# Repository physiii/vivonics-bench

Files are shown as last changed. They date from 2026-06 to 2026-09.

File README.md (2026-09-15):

# Vivonics Bench

Standalone hardware-bench repository for Vivonics shared-optical-metrology and
operator-material-screen work. The parent Vivonics repo consumes this
repository as its `bench/` Git submodule. It owns
both the Raspberry Pi measurement service and the ESP32-S3 laser-controller
firmware/circuit package.

The Pi owns the tight first-loop instrumentation:

- HDMI projector pattern display
- `IMX477` camera capture through `rpicam` / RTSP frame grabs
- USB-first control and telemetry for the ESP32-S3 four-source laser controller,
  with automatic Wi-Fi fallback
- optional `TSL2591` and `AS7341` I2C sensor snapshots
- later BPW34 photodiode data only after an ESP32/external ADC or TIA path

## Files

- `bench_service.py`: FastAPI service for projector/camera/sensor runs.
- `x1_measurement.py`: file-backed CLI smoke-test runner.
- `capture.py`, `projector.py`, `sensors.py`: hardware adapters.
- `laser_gpio.py`: Raspberry Pi GPIO outputs for red / green laser switching.
- `laser_controller_client.py`: persistent USB owner, normalized ADC telemetry,
  independent four-source control, and Wi-Fi fallback.
- `photocycle.py`: metrology and operator-screen red-linearity and green-write/red-read protocols.
- `install.sh`: user systemd service installer for `vivonics-bench`.
- `scripts/deploy_remote.sh`: workstation-to-Pi deploy helper.
- `laser_controller/`: authoritative ESP32-S3 firmware, KiCad design, review
  gates, and first-article support files for the fabricated laser controller.

## Install on the Pi

```bash
cd /home/andy/vivonics/pi  # standalone deployment path on the Pi
./install.sh
sudo raspi-config nonint do_i2c 0
```

`install.sh` creates a repo-local `.venv` so Raspberry Pi OS PEP 668 system
Python protection does not block dependency installation.

Check I2C sensor visibility:

```bash
/usr/sbin/i2cdetect -y 1
python3 x1_measurement.py sensor-check
```

Run the bench service:

```bash
./install.sh
curl http://raspberrypi.local:8090/status
curl http://raspberrypi.local:8090/sensors
```

## Laser GPIO Wiring

Use these Raspberry Pi BCM pins:

| Channel | BCM GPIO | Physical pin |
| --- | ---: | ---: |
| Red laser enable | `GPIO15` | `10` |
| Green laser enable | `GPIO24` | `18` |

Do not power or ground a laser module directly through a Pi GPIO pin. Use each
GPIO as a logic signal into a low-side MOSFET or transistor switch, with the
laser supply ground tied to Pi ground. The Pi pin drives the gate/base; laser
negative goes to the MOSFET drain / transistor collector; source / emitter goes
to ground. Keep the laser module's own current limiting or driver in place.

The camera-bench user service defaults to `VIVONICS_LIGHT_DRIVER=controller`.
It holds `/dev/ttyACM0` open, streams controller telemetry over USB, and falls
back to the current controller address at `http://192.168.1.110` when USB is
stale. The legacy GPIO path remains
available for older benches. It is active-high by default:
`Off` drives the pins low; red or green on drives the selected channel high. It
uses `10 kHz` PWM, mapping protocol levels `0..255` to `0..100%` active duty
cycle. Select the legacy path with `VIVONICS_LIGHT_DRIVER=gpio`; override pins with
`VIVONICS_RED_LASER_GPIO` and `VIVONICS_GREEN_LASER_GPIO`. Set
`VIVONICS_LASER_ACTIVE_HIGH=0` only for active-low driver hardware.

The current IR-capable USB operator camera needs explicit low-light preview
controls for the enclosed bench. Install
`systemd/50-usb-camera-demo-controls.conf` as a drop-in for
`c1-camera-rtsp.service`; it raises preview exposure and gain while keeping the
30 fps exposure envelope. This setting affects the USB RTSP/WebRTC operator
view only. It does not change direct IMX477 measurement capture.

Install `systemd/45-usb-camera-high-quality.conf` on the same service to
publish the camera's highest native real-time mode, `1920x1080 @ 30 fps`, at a
`20 Mbit/s` H.264 target. MediaMTX relays that stream to WebRTC without another
encode. The earlier `1280x720 @ 3 Mbit/s` publisher setting is not suitable for
the entropy of the low-light bench image and produces visible macroblocking.

## Reactor AD7606 Wiring and Bring-Up Notes

This is the working wiring map for the second Raspberry Pi bench
(`192.168.1.122`) that replaces the camera read path with BPW34 photodiodes
through an AD7606 module. It was brought up on `2026-05-25` on the second
reactor plane: `BUSY` began responding only after `CVA` and `CVB` were tied
together to the Pi conversion strobe.

Current reactor laser pins:

| Function | Raspberry Pi pin |
| --- | --- |
| Red laser 2N7000 gate | `GPIO15`, physical pin `10` |
| Second write laser 2N7000 gate (`green` in the service; may be blue in the reactor) | `GPIO24`, physical pin `18` |
| Infrared laser 2N7000 gate | `GPIO23`, physical pin `16` |
| Blue laser 2N7000 gate | `GPIO14`, physical pin `8` |
| 2N7000 sources / laser supply negative / ADC ground | Pi `GND`, common ground |

Observed AD7606 module digital header, top-to-bottom as shown by the board
silkscreen:

| Left column | Right column |
| --- | --- |
| `GND` | `+5V` |
| `OS1` | `OS0` |
| `RAGE` / `RANGE` | `OS2` |
| `CVB` | `CVA` |
| `RD` | `RST` |
| `BUSY` | `CS` |
| `FRST` | `VIO` |
| `DB1` | `DB0` |
| `DB3` | `DB2` |
| `DB5` | `DB4` |
| `DB7` | `DB6` |
| `DB9` | `DB8` |
| `DB11` | `DB10` |
| `DB13` | `DB12` |
| `DB15` | `DB14` |

Raspberry Pi top-down header map:

```text
Raspberry Pi 40-pin header, physical pin numbers.
Pin 1 is upper-left when looking down at the GPIO header.

 LEFT ROW                         RIGHT ROW
  1  3V3  -> AD7606 VIO           2  5V   -> AD7606 +5V
  3  GPIO2   unused               4  5V   optional +5V
  5  GPIO3   unused               6  GND  -> AD7606 GND/common
  7  GPIO4   -> AD7606 CVA+CVB    8  GPIO14 -> blue 2N7000 gate
  9  GND     common              10  GPIO15 -> red 2N7000 gate
 11  GPIO17  <- AD7606 DB0       12  GPIO18 <- AD7606 DB1
 13  GPIO27  <- AD7606 DB2       14  GND
 15  GPIO22  <- AD7606 DB3       16  GPIO23 -> infrared 2N7000 gate
 17  3V3     optional VIO        18  GPIO24 -> green 2N7000 gate
 19  GPIO10  <- AD7606 DB4       20  GND
 21  GPIO9   <- AD7606 DB5       22  GPIO25 <- AD7606 DB6
 23  GPIO11  <- AD7606 DB7       24  GPIO8  <- AD7606 DB8
 25  GND                         26  GPIO7  <- AD7606 DB9
 27  GPIO0   unused              28  GPIO1  unused
 29  GPIO5   <- AD7606 DB10      30  GND
 31  GPIO6   <- AD7606 DB11      32  GPIO12 <- AD7606 DB12
 33  GPIO13  <- AD7606 DB13      34  GND
 35  GPIO19  <- AD7606 DB14      36  GPIO16 <- AD7606 DB15
 37  GPIO26  <- AD7606 BUSY      38  GPIO20 -> AD7606 RD
 39  GND                         40  GPIO21 -> AD7606 RST
```

Fixed ADC pins:

| AD7606 pin | Draft connection | Reason |
| --- | --- | --- |
| `CS` | `GND` | Single ADC, always selected during bring-up. |
| `OS0`, `OS1`, `OS2` | `GND` | No oversampling for first tests. |
| `RAGE` / `RANGE` | `GND` | Start in the lower analog input range if supported by the module. |
| `FRST` | no connect | Optional first-data marker; not needed for first channel test. |
| `VIO` | Pi `3V3` | Keep ADC digital outputs at Pi-safe logic level. |

Do not connect or rework the AD7606 `DB0..DB15` outputs unless `VIO` is
confirmed to be tied to `3V3`; the Pi GPIO bus is not 5 V tolerant. The
validated bring-up sequence is: power the module, hold data pins as Pi inputs,
set `RD` inactive high, pulse `RST`, pulse tied `CVA`/`CVB`, confirm `BUSY`
returns low, then read the eight 16-bit parallel words.

For a one-channel BPW34 test, connect the photodiode resistor sense node to
`V1`, and connect the matching `G` input beside `V1` to the common ground. Even
when using only `V1`, the AD7606 digital read path still needs the 16-bit data
bus unless the module is separately configured for serial/SPI mode.

Verified reactor-plane response on `192.168.1.122`:

| Test state | ADC channel 1 mean | ADC channel 2 mean | Main observed delta |
| --- | ---: | ---: | --- |
| Lasers off before red test | `11214.9` | `29411.8` | baseline |
| `GPIO23` red laser at level `128` | `13622.8` | `29351.4` | `ch1 +2407.9` |
| Lasers off before second-laser test | `11220.6` | `29381.1` | baseline |
| `GPIO24` second laser at level `128` | `13927.3` | `29331.9` | `ch1 +2706.7` |

As currently wired, both laser controls produce the strongest positive optical
response on AD7606 channel `1`. Channel `2` is high at baseline but only shifts
by about `-50` to `-60` counts in these tests. Channels `3..8` stayed near zero.
The bench was left idle with both laser GPIOs off after the red test.

### 2026-05-26 Concentrated-Vial BPW34 / AD7606 Result

The concentrated-vial test did not produce an evidence-grade bR write/read
signal. The reactor bench hardware was working, but the read channel was
dominated by optical/electrical recovery from the green write pulse.

Key observed CH1 states with the concentrated vial:

| State | AD7606 CH1 mean | Notes |
| --- | ---: | --- |
| Lasers off | `11196` | dark/readout baseline |
| Red probe on | `29564` | strong red-path response |
| Green write on | `29497` | green also couples strongly into CH1 |
| Red + green on | `29618` | near the same high-count regime |

The best CH1-only direct capture ran at about `4.7 kHz`, enough to inspect the
sub-millisecond to tens-of-milliseconds bR window. In that run the immediate
green-write/red-probe bin showed about `+181` counts in `0-0.1 ms`, but the
red-off dark control showed about `+18,392` counts in the same bin. After
`0.5 ms`, the red-probe effect collapsed to the noise floor. A delayed red-read
check at `0`, `0.5`, `1`, `2`, `5`, and `10 ms` after green write did not show
a significant green-vs-control separation in the useful bins.

Artifacts from this run are in the parent workspace:

- `bench-output/reactor_direct_strong_vial_ch1fast_20260526T110410Z.json`
- `bench-output/reactor_direct_strong_vial_delayed_read_20260526T110611Z.json`

Interpretation: the AD7606 has enough code resolution for the current signal
levels; the blocker is not ADC bit depth. The BPW34 is sensitive to green light,
and the raw photodiode/resistor/ADC node stores charge when hit by the green
write pulse. That recovery transient can masquerade as an early read signal.

Next optical fixes, in priority order:

1. Add a red-pass or `650 nm` bandpass filter directly in front of the BPW34 so
   the detector sees the red probe but rejects the green write pulse.
2. Add black baffling, tubing, or a small aperture around the BPW34 so direct
   green scatter cannot reach the detector.
3. Keep paired controls for every run: green-write run, no-green control, and
   red-off dark control. A bR claim must survive all three.
4. Add a reference photodiode if possible, then subtract common laser drift and
   scattered-light pickup from the through-vial detector.

A TIA is still useful, but not because the ADC lacks resolution. A TIA can hold
the BPW34 near a fixed bias/virtual-ground point, lower the source impedance into
the AD7606, define the bandwidth with known feedback components, and recover
faster after a large light pulse. It can also support clamping or blanking during
the write pulse. A TIA will not, by itself, reject green light that physically
reaches the BPW34; optical filtering and baffling come first.

### 2026-05-26 No-Vial Green Leakage Control

After pulling the BPW34 back into the cavity to reduce side light, the vial was
removed and the reactor was tested with only laser light in the chamber. This is
the current negative control for deciding whether the immediate post-green
signal is protein or setup artifact.

No-vial CH1 steady states:

| State | AD7606 CH1 mean | Notes |
| --- | ---: | --- |
| Lasers off | `11497 +/- 191` | dark/readout baseline |
| Red probe on | `15352 +/- 189` | red path reaches CH1 |
| Green write on | `18036 +/- 195` | green still reaches CH1 strongly |
| Red + green on | `21852 +/- 191` | additive optical pickup |

The no-vial fast CH1 run reproduced the same immediate post-green transient that
appeared with the vial:

| Window | Red-probe sequence | Red-off dark control | Interpretation |
| --- | ---: | ---: | --- |
| `0-0.1 ms` | `+6372` | `+6377` | artifact, not protein |
| `0.1-0.25 ms` | `+4617` | `+4606` | artifact, not protein |
| `0.25-0.5 ms` | `+1666` | `+1635` | artifact, not protein |
| `0.5-1 ms` | `+424` | `+387` | artifact tail |

Because the same response appears with no vial and even in the red-off dark
control, the first sub-millisecond response cannot be used as bR evidence. The
exact sequence `green on -> green off -> red on` was also tested with delays of
`0`, `0.5`, `1`, `2`, `5`, and `10 ms`. After about `0.5-1 ms`, the no-vial
green-vs-control separation was mostly insignificant, but that is also the time
region where fast liquid-phase bR response may already be decaying.

Artifacts from this control were produced as local temp files:

- `/tmp/reactor_no_vial_ch1fast_20260526T114617Z.json`
- `/tmp/reactor_no_vial_delayed_read_20260526T114754Z.json`

Updated conclusion: BPW34 and AD7606 timing are not the main blocker. The
detector path is fast enough for millisecond-scale checks, but green write light
still reaches CH1 and creates detector/readout recovery that is larger than the
candidate bR readout. The next useful geometry target is that `green on` should
stay near the lasers-off CH1 baseline while `red on` remains clearly above it.
Use tighter black baffling/tubing/aperture first, then a red-pass or `650 nm`
filter directly in front of the BPW34.

Run a file-backed red linearity check:

```bash
python3 x1_measurement.py linearity --output-dir /tmp/vivonics_x1_linearity
```

Deploy from the workstation:

```bash
scripts/deploy_remote.sh andy@192.168.1.174 /home/andy/vivonics/pi
```

Claim boundary: these scripts are instrumentation for shared-optical-metrology
and operator-screen smoke tests. They do not promote Carolina `NRC-1` material to evidence-grade bR or purified
purple-membrane claims.

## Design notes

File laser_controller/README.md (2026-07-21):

# Vivonics Laser Controller

This directory is the authoritative bench package for the fabricated ESP32-S3
laser-controller board. Firmware and circuit artifacts live together so a code
change, board assumption, and first-article measurement can be reviewed against
the same bench-repository commit.

## Package map

- [`code/`](code/README.md): ESP-IDF firmware, host tests, build profiles, and
  the isolated AD7606 diagnostic.
- [`circuits/`](circuits/README.md): KiCad source, fabrication artifacts,
  electrical review scripts, signoffs, and calibration templates.

The old parent-repository locations `firmware/laser_controller/` and
`bench/circuits/` are retired. Make laser-controller changes only under this
directory. In the main Vivonics checkout the full paths are
`bench/laser_controller/code/` and `bench/laser_controller/circuits/`.

## Verification from the bench repository root

```bash
laser_controller/code/run-host-tests.sh
laser_controller/code/build-container.sh
laser_controller/code/build-validation-container.sh
laser_controller/code/build-laser-test-container.sh
laser_controller/code/build-dashboard-container.sh
python3 laser_controller/circuits/run_laser_controller_review.py
```

The firmware wrappers work both in a standalone clone of `vivonics-bench` and
when this repository is checked out as the parent Vivonics repo's `bench/`
submodule. The circuit review regenerates its local audit report under
`circuits/review/generated/`.

## Evidence boundary

Code and CAD checks establish reproducible software and design-review evidence;
they do not replace current-limited board bring-up, oscilloscope captures,
optical-power calibration, temperature measurements, or fail-safe testing. The
parent Vivonics repository owns experimental records under `bench-output/` and
program-level interpretations under `docs/program/`.

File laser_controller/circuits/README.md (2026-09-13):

# Laser Controller — 1ch × 4λ: on-board SFH2201 PD → 4ch TIA + monitor-PD feedback + ESP32-S3 + 4× laser drivers

This is the authoritative circuit tree at
`laser_controller/circuits/` in the `vivonics-bench` repository. Firmware for
this exact board is maintained alongside it under `laser_controller/code/`.

Bench controller for the bR index/phase read. **One optical channel, four wavelengths**
(IR / RED / GREEN / BLUE). Each wavelength has a precision **constant-current laser sink**
(with current-sense feedback) and one **on-board Osram SFH2201 clear Si PIN photodiode**
reverse-biased into an **OPA380 transimpedance amp**. The four TIA outputs go to the
on-board **AD7606BSTZ-4**. An **ESP32-S3-WROOM-1** real-time co-processor drives the 4 PWM laser
controls, reads the 4 current-sense voltages and 4 internal laser monitor-photodiode
voltages on its own ADC pins, issues hardware-timed **CONVST** to the AD7606, clocks the
AD7606 serial outputs, is programmed
and powered over **native USB (Mini-B)**, and talks to the Raspberry Pi over **UART**.

**Why a single PD per wavelength (not a quad/centroid PD):** the production reader is a
Gpixel line sensor doing a *per-pixel intensity* read, and the bench's dual-pinhole
interferometer is also a single-PD intensity read — so one broadband PD per beam is the
faithful, JLCPCB-assemblable proxy. Beam-deflection/centroid sensing (the quad-PD's only
unique capability) is a fallback the production engine deliberately engineers out. The
program rationale lives in the parent Vivonics repository:
[`ARCHITECTURE.md`](https://github.com/physiii/vivonics/blob/main/docs/ARCHITECTURE.md),
[`SZEGED_BR_SWITCHING_LINEAGE_AND_INDEX_READ_FINDINGS_2026-06-22.md`](https://github.com/physiii/vivonics/blob/main/docs/program/SZEGED_BR_SWITCHING_LINEAGE_AND_INDEX_READ_FINDINGS_2026-06-22.md),
and the closed dual-pinhole branch in
[`LITERATURE_SATURATION_LEDGER.md`](https://github.com/physiii/vivonics/blob/main/docs/program/LITERATURE_SATURATION_LEDGER.md).

## Files

All sheets are **code-generated** from `gen_laser_controller.py`. The MCU sheet uses the
copied access-controller ESP32-S3 page with the real
`Espressif:ESP32-S3-WROOM-1` symbol, CP2102N USB-UART, two USB Mini-B entries,
discrete ESD/VBUS support, and reset/program/factory buttons. **Do not
hand-edit the generated `.kicad_sch` files**; edit the generator or copied-source
adapter flow deliberately and re-run:

```
python3 gen_laser_controller.py
```

| File | Role |
|---|---|
| `gen_laser_controller.py` | Generator for root, TIA, laser-driver, MCU, power/IO sheets + BOM. |
| `adapt_mcu.py` | Compatibility wrapper for older flows; it verifies the imported MCU sheet exists and does not overwrite the copied access-controller page. |
| `gen_pcb.py` | Placement-staging generator: keeps only the 90 x 50 mm board outline, stages schematic footprints outside the outline, and assigns PCB pad nets for manual placement/ratsnest work. |
| `check_laser_controller_pcb.py` | Board-level guardrail: verifies generated PCB pad nets against the exported schematic netlist. |
| `check_schematic_hierarchy_labels.py` | Schematic hierarchy/label guardrail: verifies root sheet pins, pin directions, child hierarchical label shapes, and intentional root global-label whitelist. |
| `check_schematic_presentation.py` | Schematic presentation guardrail: verifies generated net labels clear symbols/text/other labels, generated wires do not enter symbol bodies, and symbol pin anchors/strokes touch their glyphs. |
| `check_laser_controller_sources.py` | Source/register guardrail: verifies every exported MPN/LCSC token is represented in the source register or part notes, every exported net has a specific electrical-intent mapping, and every exported component pin has a component-pin-level role. |
| `check_part_notes_completeness.py` | Part-note guardrail: verifies critical datasheet notes still carry pinout, layout, risk, and checker-evidence phrases. |
| `check_source_documents.py` | Source-document guardrail: verifies required datasheet/manufacturer URLs and required local source/footprint artifacts are present; reports secondary/distributor source risks and vendor-CDN probe failures as warnings. |
| `check_laser_controller_release_gate.py` | Generated-copper fabrication gate: fails on split signal/control nets, unacceptable laser cathode/anode current routes, or missing laser sense-return GND vias; poured rail/zone connectivity is checked by KiCad refill/DRC. |
| `check_layout_review_geometry.py` | Focused layout-geometry gate for buck local loops, USB ESD placement, OPA380 summing-node loops, monitor-PD raw paths, and laser-current sense loops. |
| `check_laser_controller_release_readiness.py` | Open first-article/production blocker gate: keeps calibration, firmware, thermal, protection, procurement, and measured bring-up blockers visible in the review wrapper. |
| `check_jlcpcb_order_package.py` | JLCPCB prototype order-package gate: verifies Gerber/drill zip contents, BOM/POS designator match, J7 C192300 2x4 SMD header metadata, required board labels, the flat transfer archive, and the U1-U4/RV1-RV8 physical orientation gate. |
| `check_power_thermal_budget.py` | AP2112 `+3V3` thermal guardrail for bench/no-RF versus sustained RF policies. |
| `check_power_bringup_template.py` | First-article power/input bring-up measurement-template guardrail for J5/VIN24, AP632 rails, post-OR +5V, LASER_V+, and AP2112 +3V3 rows. |
| `check_vin24_input_protection.py` | VIN_24V bench-topology and production input-protection guardrail for J5/J6, adapter/harness limit, fuse/TVS/reverse-protection decisions. |
| `check_laser_driver_control_loop.py` | Laser-driver control-loop guardrail for PWM divider topology, TLV9001 input/output range, AO3400A gate drive, and the hardware-clamp gate-margin expected fail. |
| `check_laser_driver_package_pcb.py` | Laser-driver package/PCB guardrail: verifies U5-U8 TLV9001 and Q1-Q4 AO3400A schematic pin nets, local sense/command/gate/compensation component identities, current PCB pad nets, and KiCad SOT-23-5/SOT-23/2512/0603/0402/0603-cap geometry. |
| `check_laser_diode_footprints.py` | Direct LD1-LD4 TO-can guardrail: verifies selected diode MPN/footprint identities, schematic pin nets, current PCB pad nets, LD4 case no-connect, `MPD_RAW4` spare/open, and installed KiCad TO18/TO56 pad geometry. |
| `check_orientation_polarity_pcb.py` | Physical orientation/polarity guardrail for the mirror-risk parts found in the JLCPCB preview: U1-U4 OPA380 SOIC-8 pad order/rotation/pin nets and RV1-RV8 Bourns 3224W wiper geometry/nets. |
| `repair_orientation_sensitive_footprints.py` | Narrow, idempotent repair script for the confirmed mirrored U1-U4 OPA380 and RV5-RV8 Bourns 3224W embedded PCB footprints and directly attached local escape routing. |
| `check_monitor_pd_package_pcb.py` | Monitor-PD package/PCB guardrail: verifies U12 INA4180/U13 LM4040 pin nets, local 240 ohm sense, 1 k / 100 nF ADC filters, R41/C35/C36 support parts, current PCB pad nets, LD4 case no-connect, and KiCad TSSOP-14/SOT-23/0603/0402 geometry. |
| `check_laser_current_budget.py` | Laser current-loop guardrail for the PWM clamp, selected laser-diode current limits, sense resistor, AO3400A heat, and `LASER_V+` headroom. |
| `check_laser_bringup_template.py` | First-article laser bring-up measurement-template guardrail for LD1-LD4 current-limit, safety-fixture, optical-output, temperature, and firmware-shutoff rows. |
| `check_tia_readout_budget.py` | SFH2201/OPA380 signal-PD TIA guardrail: exact topology into AD7606, VBIAS/common-mode bound, OPA380 output headroom, and bright-ambient expected-fail range check. |
| `check_optical_calibration_template.py` | First-article optical/readout calibration-template guardrail for LD1-LD4 monitor-PD handling, D1-D4 signal-PD calibration, and U14 V1-V4 AD7606 known-input readback rows. |
| `check_firmware_validation_template.py` | First-article AD7606 firmware/readback validation-template guardrail for timing, both DOUT lines, scaling, channel order, and known-input rows. |
| `check_ad7606_package_pcb.py` | AD7606 package/PCB guardrail: verifies U14 schematic pin nets, C51-C60 AVCC/VDRIVE/REGCAP/reference capacitor identities and pad nets, current PCB pad nets, FRSTDATA no-connect, and installed KiCad LQFP-64 pad geometry. |
| `check_ap6320x_package_pcb.py` | AP63205/AP63200 package/PCB guardrail: verifies U15/U16 schematic pin nets, current PCB pad nets, KiCad TSOT-23-6 pad geometry, and local L1/L2 inductor footprint geometry. |
| `check_passive_derating.py` | Passive voltage/power guardrail for every assembled capacitor, resistor, and SMD trimmer MPN in the exported netlist. |
| `check_procurement_release_template.py` | Quote-time procurement and production-derating template guardrail for BOM/POS quote acceptance, substitutions, pulse/surge derating, board-temperature evidence, and order archive linkage. |
| `check_first_article_release_evidence.py` | First-article release evidence ledger guardrail: requires explicit closure rows for all deferred blocker categories and keeps them open until linked measurement/procurement/firmware evidence exists. |
| `run_laser_controller_review.py` | One-command review wrapper for available gates, JLCPCB order status, deferred first-article/production blockers, and KiCad ERC/DRC/parity reporting. |
| `laser_controller.kicad_sch` | Root sheet — sheet symbols + global-label interconnect (A2). |
| `tia_ir.kicad_sch`, `tia_red.kicad_sch`, `tia_green.kicad_sch`, `tia_blue.kicad_sch` | Four on-board PD + OPA380 TIA sheets with globally unique designators. |
| `laser_ir.kicad_sch`, `laser_red.kicad_sch`, `laser_green.kicad_sch`, `laser_blue.kicad_sch` | Four constant-current laser sink sheets with globally unique designators; each sheet has a direct through-hole TO-can footprint so `LD_K`, common `LD_A/PD_K/case`, and `PD_A -> MPD_RAW` are visible. |
| `mcu.kicad_sch` | ESP32-S3-WROOM-1 + CP2102N USB-UART + two USB Mini-B connectors + discrete USB/VBUS ESD + reset/program/factory buttons. |
| `power_io.kicad_sch` | 5V OR-ing, laser supply, on-board AD7606-4 signal ADC, and shared INA4180/LM4040 monitor-PD front end. |
| `laser_controller_bom_jlcpcb.csv` | JLCPCB assembly CSV (Comment, Designator, Footprint, LCSC) for SMT plus the J5/J6 through-hole connector assembly rows; direct laser cans are listed separately. |
| `fab/laser_controller_pos.csv` | JLCPCB CPL CSV converted to the five-column upload format (`Designator,Mid X,Mid Y,Layer,Rotation`); designators match the JLCPCB BOM. |
| `laser_controller_gerbers.zip` | Current PCB Gerber/drill zip for JLCPCB PCB fabrication upload. |
| `laser_controller_jlcpcb_package.zip` | Flat review/transfer archive containing Gerber/drill files plus BOM and JLCPCB-format CPL. |
| `review/journal/2026-07-06-jlcpcb-laser-controller-order.md` | JLCPCB first-article order record for work order `W2026070704037950`; excludes shipping/billing PII and card details. |
| `laser_controller.kicad_pro` | KiCad 7 project file. |
| `LASER_MONITOR_PD_FEEDBACK.md` | Design note for the internal laser monitor photodiode feedback path and production APC implications. |
| `LASER_CURRENT_THERMAL_BUDGET.md` | Laser current-loop thermal budget and common-rail bench limitation. |
| `POWER_TREE.md` | Rail/source/load review and release gates for 24 V barrel/RJ45 input, USB VBUS, BUCK_5V, +5V, +3V3, LASER_V+, and GND. |
| `POWER_THERMAL_BUDGET.md` | AP2112/ESP32-S3 thermal budget and bench-vs-production regulator decision. |
| `../../docs/source-register.md` | Datasheet/source register for active components, passives, manufacturing capability, and open source gaps. |
| `../../docs/part-notes/` | Compact datasheet notes for package-sensitive and behavior-sensitive parts. |

Every SMT component carries a **hidden `LCSC` field + `Part Number` (MPN) field** — exactly
the access-controller convention, so clicking a part in Eeschema shows its LCSC number and
the JLCPCB BOM exports straight from the `LCSC` column.

## Topology

```
PD + TIA CHANNEL (×4 = IR / RED / GREEN / BLUE)  — on-board, no off-board optics header
  Osram SFH2201 clear Si PIN PD (D1):  cathode → +5V via RB(1k)+CB bypass = reverse bias
        anode → OPA380AID −IN (summing node)
  Rf = RVFB (2M feedback trim, wiper tied to output side) ∥ Cf = C1 (10pF) ;  +IN = VBIAS (RV11 10k trim + RC)
  V_OUT = VBIAS + I_pd·Rf  →  U14 AD7606BSTZ-4 on-board ADC
  check_tia_readout_budget.py passes the current topology but shows this is a high-sensitivity bench range:
  at VBIAS=1.5V and RF=2M, OPA380 headroom is about +1.40 uA / -0.70 uA before clipping.
  TIA readout range and optical calibration remain release blockers.

LASER DRIVER (×4, one per wavelength)
  PWM_IN → 10k/1µF filter with per-channel limiter pulldown → TLV9001(+) ; TLV9001 OUT →
  1k → AO3400A gate ; source → 10Ω 2512 2W sense → GND
  I_laser = V_ctrl / 10Ω ; full-scale command is per color:
  IR≈38.0mA, red≈23.0mA, green≈76.2mA, blue≈105.5mA.
  The selected max-current and per-channel analog-limit cases pass the
  TLV9001/AO3400A range checks; optical output, duty cycle, loop dynamics, and
  board temperature remain bring-up measurements.
  Sense top → FB (op-amp −) and 1k → ISENSE (isolates the ADC tap from the loop) ;
  10pF loop-comp ; AO3400A drain → LASER_N (direct LDx footprint) ; laser-can model:
  LD_K → LASER_N, common LD_A/PD_K/case → LASER_V+, PD_A → MPD_RAW
  LASER_V+ is a shared bench rail: set it from the actual diode Vf/current table so the
  AO3400A does not become the heat sink.

MCU  ESP32-S3-WROOM-1 (2.4 GHz Wi-Fi 802.11 b/g/n / Bluetooth LE / native USB)
  USB Mini-B J1 → discrete ESD → CP2102N USB-UART → ESP32 UART0/auto-reset network
  USB Mini-B J2 → discrete ESD → ESP32 native USB-Serial/JTAG
  (D+ = GPIO20 / module pin 14, D− = GPIO19 / module pin 13)
  4× PWM → laser drivers · 4× ISENSE ← laser current-sense · 4× MPD ← internal monitor PDs ·
  CONVST/SCLK/CS/RESET → AD7606 · BUSY/DOUTA/DOUTB ← AD7606
  VDD3P3 from AP2112K-3.3 LDO (bench/no-RF thermal policy only) ; EN pulled up + 1uF + reset button ;
  GPIO0/BOOT pulled up + 1uF with local PROG button ; FACT button on GPIO1

POWER / IO
  VIN_24V = J5 center-positive barrel jack + J6 RJ45 pins 4/5 copied from access-controller
  VIN_24V is presently a direct bench input: no schematic fuse/PTC/TVS/
  reverse-protection/eFuse stage sits between J5/J6 and the AP632 buck inputs.
  BUCK_5V = U15 AP63205WU-7 from VIN_24V ; D6 ORs it with USB VBUS through D5 into +5V
  +3V3 = AP2112K-3.3 from +5V
  LASER_V+ = U16 AP63200WU-7 from VIN_24V, set near 9.38V for the shared bench laser rail
  U14 AD7606BSTZ-4RL → VOUT1..4, CONVST, SCLK, CS, BUSY, RESET, DOUTA, DOUTB
  LD1..LD4 direct TO-can footprints carry LASER_N/MPD_RAW pairs + LASER_V+
  MPD_RAWx -> 240R sense -> MPD_BIAS ; INA4180A1 gain 20 -> 1k/100nF -> MPDx ESP32 ADC
  LM4040C50 holds LASER_V+ - MPD_BIAS near 5V for PLT5-style/A-code monitor diodes
```

The third monitor-photodiode pin present on several raw laser diodes is exposed as
`MPD_RAW1..4` and converted to ESP32 ADC telemetry as `MPD1..4`. This is useful for
source-power telemetry, slow firmware optical-power correction, and production APC,
but it is not a replacement for the transmitted-light/sample photodiode path. See
[`LASER_MONITOR_PD_FEEDBACK.md`](LASER_MONITOR_PD_FEEDBACK.md) before changing diode
footprints, pin-code assumptions, or production driver selection.

The wavelength of each channel is set by the firing laser (the sheet names carry IR/RED/
GREEN/BLUE); the SFH2201 is broadband (300–1100 nm) so the same PD detects all four.

## BOM — verified LCSC numbers (2026-06-30)

`laser_controller_bom_jlcpcb.csv` is the JLCPCB assembly CSV generated from
parts with populated LCSC fields. It includes SMT plus the J5 barrel jack and
J6 RJ45 through-hole connector rows for JLCPCB THT/wave/manual connector
assembly. It intentionally excludes the direct laser-can footprints; those are
separate hand-installed optical items listed below.

### SMT (JLCPCB assembled)

| Part | Value | LCSC | JLC tier | Notes |
|---|---|---|---|---|
| U1–U4 | OPA380AID (SOIC-8) | **C201677** | Extended | TIA op-amp; low stock + highest BOM cost — buy a buffer. |
| U5–U8 | TLV9001IDBVR (SOT-23-5) | **C398363** | Extended | laser-driver op-amp. |
| U10 | CP2102N-A02-GQFN28R (QFN-28 EP) | **C964632** | Extended | USB-UART bridge copied from the access-controller MCU sheet. |
| U11 | AP2112K-3.3 (SOT-23-5) | **C51118** | Basic | 3V3 LDO for bench USB/UART with RF disabled; sustained Wi-Fi/BLE needs a buck or measured duty-cycle proof. |
| U12 | INA4180A1IPWR (TSSOP-14) | **C2057528** | — | quad high-side monitor-PD current-sense amplifier, gain 20. |
| U13 | LM4040C50IDBZR (SOT-23-3) | **C69316** | — | 5.0 V shunt reference for `MPD_BIAS`; DBZ pin 3 tied to anode. |
| U14 | AD7606BSTZ-4RL (LQFP-64) | **C51512** | Extended | 4-channel simultaneous signal-PD ADC; `VOUT1..4` into V1/V2/V3/V4, serial readback to ESP32. |
| U9 | **ESP32-S3-WROOM-1** | **C2913199** | Extended | MCU — exact C-number used on the access-controller; native USB. |
| D1–D4 | **Osram SFH2201** photodiode | **C2900216** | Extended | on-board clear Si PIN PD, 300–1100 nm (`OptoDevice:Osram_SFH2201`). One per wavelength. |
| Q1–Q4 | AO3400A N-MOSFET (SOT-23) | **C20917** | Basic | laser low-side sink pass device. |
| D5–D6 | MDD SS14 (SMA/DO-214AC) | **C2480** | Basic | 5V OR-ing Schottky, 40V/1A. D5 = USB `VBUS_5V`, D6 = onboard `BUCK_5V`; 2026-07-04 signoff confirms C2480 identity and polarity. |
| D7-D14 | LESD5D5.0CT1G(UMW) / 1N5819HW VBUS support | **C5199850 / C82544** | — | copied MCU-sheet USB data/VBUS ESD and USB VBUS isolation. |
| U15 | AP63205WU-7 (TSOT-23-6) | **C2071056** | — | 24 V input to onboard 5 V buck; output `BUCK_5V` feeds D6. |
| U16 | AP63200WU-7 (TSOT-23-6) | **C2071868** | — | 24 V input to adjustable shared bench `LASER_V+` buck. |
| L1 | 4.7uH shielded inductor | **C408410** | — | AP63205 5 V buck inductor, copied from access-controller libraries. |
| L2 | 10uH shielded inductor | **C98364** | — | AP63200 laser buck inductor, copied from access-controller libraries. |
| RV1–RV4 | 10k SMD trimmer | **C81348** | Extended | VBIAS, Bourns **3224W-1-103E** (SMD, JLCPCB-mountable); pin 2 wiper orientation signed off on 2026-07-04. |
| RV5–RV8 | 2M SMD trimmer | **C116323** | Extended | TIA feedback trim, Bourns **3224W-1-205E**, pin 2 wiper tied to OPA380 output side; orientation signed off on 2026-07-04. |
| R (10k) | 10k 0603 1% | **C844918** | — | VBIAS / EN / BOOT pull-up resistors. |
| R (240Ω) | 240Ω 0603 1% | **C103446** | Extended | monitor-PD high-side sense resistors, RALEC `RTT032400FTP`. |
| R (2.49k) | 2.49k 0603 1% | **C22908** | Extended | LM4040/`MPD_BIAS` sink resistor, UNI-ROYAL `0603WAF2491T5E`. |
| R61/R62/C69 | 237k / 22.1k / 100pF feedback set | **C2998117 / C2929993 / C1546** | — | AP63200 feedback divider and feed-forward capacitor for about 9.38 V `LASER_V+`. |
| R (1k) | 1k 0603 1% | **C2907002** | — | gate / ISENSE-isolation / PD-bias / monitor-ADC isolation resistor. |
| R21/R26/R31/R36 | 1.3k / 750Ω / 3k / 4.7k 0603 1% | **C22767 / C23241 / C4211 / C23162** | Basic | Per-channel PWM command limiter pulldowns for IR / red / green / blue. |
| R (10Ω) | 10Ω 2512 2W 1% | **C5123624** | Basic | laser source-sense resistor. |
| C (10pF) | 10pF C0G 0603 | **C106245** | Extended | Cf / loop-comp. |
| C (1µF) | 1µF 0402 25V X5R | **C7472946** | — | PWM filter / PD-bias bypass / LDO input. |
| C61-C62 | 10µF 1206 50V X7R | **C89632** | Extended | high-voltage `VIN_24V` ceramic input capacitors for AP632 local bypass. |
| C70 | 22µF 100V SMD electrolytic | **C970665** | Extended | `VIN_24V` input bulk capacitor, DMBJ `RVT2A220M0810 22UF 100V`; same D8xL10.2 mm package as the short-stock previous C70 part. |
| C (100nF) | 100nF 0402 16V X7R | **C83056** | — | decoupling and monitor-PD low-pass filters. |
| C (10µF) | 10µF 0805 25V X5R | **C318691** | — | bulk decoupling. |
| C64-C65/C67-C68 | 22µF 0805 25V X5R | **C45783** | Basic | AP63205/AP63200 buck output capacitor banks, 2x22µF per rail. |
| J1-J2 | USB Mini-B receptacle | **C46391** | (JLC assy) | `920-462A2021S10101` metadata on the copied Mini-B land pattern. |

### THT connector assembly (JLCPCB assembled if accepted)

| Part | Value | Notes |
|---|---|---|
| J5 | 24 V DC barrel jack, `Open_Automation:BarrelJack_OD5.5_ID2.5` | Center-positive 24 V input, GANGYUAN `DC-470-2.1GP` / LCSC **C194407**, copied from the access-controller libraries. |
| J6 | 24 V RJ45 power input, `Connector_RJ:RJ45_Amphenol_RJHSE538X` | RJ45 pins 4/5 to `VIN_24V`, pins 7/8/9/11 to GND, pins 10/12 through 10k LED/contact resistors to `VIN_24V` and `+3V3`, Ckmtw `R-RJ45R08P-C000` / LCSC **C386757**, copied from the access-controller Ethernet sheet and libraries. |

### Hand-add / not in JLCPCB assembly

| Part | Value | Notes |
|---|---|---|
| LD1 | D7805I, `OptoDevice:LaserDiode_TO18-D5.6-3` | Direct IR laser can. |
| LD2 | D6505I, `OptoDevice:LaserDiode_TO18-D5.6-3` | Direct red laser can. |
| LD3 | PLT5 520EB_P, `OptoDevice:LaserDiode_TO56-3` | Direct green laser can. |
| LD4 | PLT5 450GB, `OptoDevice:LaserDiode_TO56-3` | Direct blue laser can; case pad is intentionally no-connect and `MPD_RAW4` stays spare/open. |

## ⚠ Before PCB layout — required pin-accuracy pass

Connectivity is validated by KiCad **netlist export — 150 exported nets, zero unintended tied
bench signals**. The USB `ID` pin, LDO `NC` pin, OPA380 `NC` pins 1/5/8, and unused ESP32-S3
pads are deliberate no-connects; `check_laser_controller_netlist.py` now fails any single-node
exported net outside that explicit no-connect allowlist. It also asserts exact value/footprint/MPN/LCSC
identity for all 160 schematic components and package pin functions for the datasheet-sensitive
parts: OPA380, TLV9001, AP2112K, CP2102N, ESP32-S3-WROOM-1, INA4180, LM4040, AD7606, AO3400A,
SFH2201, SS14, and USB Mini-B. It also asserts exact `+5V`, `+3V3`, and `GND` rail membership so broad power
rails cannot hide a stray or missing power pin. The review file
`review/2026-06-25_datasheet_pin_matrix.md` summarizes the datasheet pin decisions and the
script guardrails that enforce them. `check_laser_controller_sources.py` also fails if any
exported net or component pin falls back to a generic "review required" intent in the full
net/pin inventory. `check_source_documents.py` separately checks required primary datasheet
URLs, the inherited access-controller ESP32-S3 source sheet, the local OPA380 datasheet copy,
and package-sensitive KiCad footprint files; secondary distributor/order sources remain
warnings rather than silent assumptions, and vendor-CDN probe failures such as ST remain
explicit manual release-time checks.
`check_usb_vbus_interface.py` separately asserts the copied USB/VBUS support
block: J1 USB-UART, J2 ESP32-S3 native USB, Mini-B pins 1-6, CP2102N QFN28
pins 4/5/8, ESP32-S3 module pins 13/14, discrete ESD clamps, 1N5819HW VBUS
isolation, D5 +5 V OR-ing, the CP2102N 22.1 k / 47.5 k VBUS divider, RST
pull-up, UART, EN/BOOT auto-reset, and USB ID no-connects. Its
`connector-source-match` policy passes only when the active metadata is
`920-462A2021S10101` / **C46391** on the copied Mini-B land pattern.
`check_esp32_reset_boot_controls.py` separately asserts the copied reset/boot
support block: EN 10 k / 1 uF / RESET button, GPIO0 BOOT 10 k / 1 uF / PROG
button, GPIO1 FACT button, CP2102N QFN28 DTR/RTS into the Q5/Q6 auto-reset
transistor network, CP2102N RST/SUSPEND pulls, and IO13/IO14 pulls.
`check_schematic_hierarchy_labels.py` separately enforces the intended root/child-sheet
interface: 10 root sheets, typed sheet pins, the whitelisted root global labels,
matching typed child hierarchical labels, and zero child-sheet global labels.
`check_schematic_presentation.py` separately enforces reviewability of the generated sheets:
net labels must clear symbol bodies, visible reference/value text, and other labels, generated
wire segments must not pass through component bodies, and every generated wire endpoint must land
on a real connection object. It also checks that custom-symbol pin anchors/strokes touch the symbol
glyph, preventing visually disconnected parts. Generated symbol origins, wire endpoints, labels,
junctions, no-connect markers, sheet pins, and custom-symbol pin anchors must stay on the 50 mil
schematic grid.
The current PCB has explicit pad nets verified by `check_laser_controller_pcb.py` so
missing pad-net assignment on quoted/bare footprint pads is caught before routing. The same
PCB check verifies net-class membership for laser current, power rails, USB,
TIA-sensitive analog, monitor/ADC telemetry, laser control, and digital control nets,
plus the explicit four-layer stackup (`F.Cu`, `In1.Cu`, `In2.Cu`, `B.Cu`) and
the ESP32 footprint antenna keepout. It also checks pad-to-pad placement distances
covering the USB connectors, discrete USB ESD clamps, AP2112 capacitors, ESP32
local 3V3 decoupling, EN capacitor, EN pull-up, BOOT pull-up, every TIA
photodiode/input/feedback/decoupling/bias cluster, every laser-driver
gate/sense/control/compensation cluster, and every monitor-PD
sense/reference/ADC-isolation cluster near the direct laser footprints.

The current board artifact is routed for the available custom checks: measured
evidence is 181 physical footprints, including two grounded board-only mounting
holes, 1611 routed copper segments, 236 vias, four board-level zones, and one
footprint-internal ESP32 antenna keepout. The old laser/MPD header footprint is
not present. The PCB checker verifies intentional unnetted pad instances so
OPA380 NC pads, AP2112 NC, USB ID, unused ESP32 pads, paste-only pads, and
mechanical pads are explicit rather than silent floating copper. It also verifies
copper uses named nets, positive widths, declared layers, net-class clearance,
duplicate via stacks, board-boundary compliance, unsupported dangling copper
endpoints/vias, non-power via policy, critical local-route connectivity, USB
D+/D- length/skew, and route-layer/route-width policy.
It also enforces a sensitive local-route length policy on 40 nets: raw laser
monitor-PD inputs (`MPD_RAWx`) must stay at or below 12 mm, OPA380 summing nodes
at or below 12 mm, photodiode cathode/bias stubs at or below 5 mm, local trim/
bias nodes at 9-18 mm by function, laser gate nodes at or below 3 mm, laser
op-amp output nodes at or below 7 mm, and laser sense-feedback loops at or
below 12.5 mm.
Current blocker: the custom PCB, generated-copper, focused layout-geometry, and
return-path signoff gates pass, but the board is not fabrication-released until
KiCad ERC with schematic parity evidence, native KiCad DRC/parity,
procurement/source checks, and bring-up measurement blockers are closed. A
2026-07-04 GUI DRC screenshot is
captured in `review/signoff/2026-07-04-kicad-drc-zero-violations.md` and shows
0 violations / 0 unconnected items with zone refill enabled, but schematic
parity was not run in that DRC dialog. The checker also enforces same-layer spacing
from laser-current copper to `TIA_Sensitive`, `MPD_RAWx`, and filtered
`Monitor_ADC` copper.
`check_power_thermal_budget.py` separately enforces the AP2112 `+3V3` bench/no-RF thermal
policy; it intentionally fails sustained Wi-Fi/BLE load cases on the current SOT-25 LDO.
`check_ap6320x_package_pcb.py` separately enforces the AP63205/AP63200 package
pin nets against the current PCB pads: U15/U16 `FB/EN/IN/GND/SW/BST`, L1/L2,
bootstrap caps, output caps, and U16 feedback parts. It also checks the installed
KiCad TSOT-23-6 footprint geometry and local Open_Automation L1/L2 footprints.
`check_buck_input_power_budget.py` separately enforces the AP63205/AP63200 pinout,
feedback, input-current, and inductor-stress policy. The selected-diode 9.3 V
max-current reference and all-channel per-channel analog-limit case pass the
500 mA J5 bench input rating. The same checker also keeps the AP632 production
component guard visible: C64+C65/C67+C68 now provide 44 uF per buck output with
2x22 uF 25 V ceramics, and C61+C62 are 20 uF nominal VIN ceramic input
capacitance.
`check_laser_current_budget.py` separately checks the laser command clamp, selected
LD1-LD4 current limits, sense resistor power, AO3400A heat, and safe `LASER_V+`
window for the selected diode forward voltage. The selected-diode policies show
that the present 9.3 V common-rail reference passes the selected typical-current,
max-current, and per-channel analog-limit cases. The generic high-rail
expected-fail policies remain to show why `LASER_V+` and commanded current need
per-diode review.
`check_passive_derating.py` verifies all assembled passive MPNs against explicit bench
voltage/power ratings; current worst cases are `R57` at 40.0% resistor power,
the `100nF MPD bias` capacitor at 31.6% of rating, and `R61` at 13.3% resistor voltage.
The `VIN_24V` input capacitors are at 24.0% of their 100 V rating under nominal
24 V steady-state input.
The generated inventory separately reports routed copper width/via geometry by
net class and whole-board explicit route connectivity. In the current recovered
placement PCB those route sections are empty: signal/control multi-pad nets are
not explicitly routed, `+3V3`/`+5V`/`VIN_24V`/`BUCK_5V`/`GND`/`LASER_V+`/`VBUS_5V` still need
pours or trunks, and the laser sense returns have no high-current GND vias.
Netlist export is *not* full
ERC; `PWR_FLAG`s declare externally-supplied rails, but GUI ERC still must be run and reviewed
before release. Items to
datasheet-check before routing:

1. **ESP32-S3-WROOM-1 symbol pinout.** The schematic uses the real Espressif symbol and
   `RF_Module:ESP32-S3-WROOM-1` footprint. Netlist audit confirms USB D− on GPIO19/module
   pin 13, USB D+ on GPIO20/module pin 14, GPIO0/BOOT pulled up with local PROG button, and all
   unused pads marked no-connect. Still mind strapping pins (GPIO0/3/45/46) and the antenna
   keep-out during layout.
2. **SFH2201 polarity.** `OptoDevice:Osram_SFH2201` pad 1 = cathode, pad 2 = anode (matches
   the KiCad `D_Photo` symbol convention used here). Confirm the orientation mark in bring-up.
3. **USB Mini-B land.** J1/J2 use `920-462A2021S10101` /
   **C46391** metadata on the KiCad Mini-B footprint; check connector pin-1, shield pad
   6 to GND, board-edge orientation, and final JLCPCB quote acceptance.

### Design review — folded into the generator

- **LDO brownout/thermal** — AP2112K-3.3 avoids the AMS1117 dropout problem, but it is accepted
  only for the bench USB/UART no-RF policy. The SOT-25 thermal budget fails sustained
  Wi-Fi/BLE current and production wireless should use a buck regulator or larger proven supply.
- **PD reverse bias** — SFH2201 cathode → +5V via RB(1k) + CB bypass; anode → OPA380 −IN;
  `V_OUT = VBIAS + I_pd·Rf` (positive-going).
- **ERC power sources** — `PWR_FLAG`s on +5V, +3V3-source, LASER_V+, VBUS_5V.
- **Decoupling** — 100 nF at every OPA380 and TLV9001 V+.
- **VBIAS range** — series 10 k bounds the trim to ≤2.5 V, inside the OPA380 input CM.
- **Laser loop** — TLV9001 drives AO3400A gate through 1 k; 10 pF compensation cap + 1 k
  resistor isolate the ISENSE tap from the current-sense feedback node. The 30 k pulldown on
  the filtered command node limits nominal full-scale current to about 248 mA. The shared
  `LASER_V+` rail must be chosen from the actual diode forward-voltage table; too much rail
  headroom is dissipated in the AO3400A.
- **Monitor PD path** — `MPD_RAWx` feeds a 240 ohm high-side sense resistor into
  `MPD_BIAS`; INA4180A1 gain 20 drives a 1 k / 100 nF ADC-side filter into `MPDx`.
  LM4040C50 holds `LASER_V+ - MPD_BIAS` near 5 V. At `LASER_V+ = 10.5 V`, typical
  PLT5 520EB_P monitor current around 150 uA maps to about 0.72 V at the ESP32 ADC and
  about 4.96 V monitor-PD reverse bias. This front end is pin-topology compatible with
  selected `D7805I`, `D6505I`, and `PLT5 520EB_P`, and the selected high-end monitor
  currents now fit the local ADC-headroom guard: D7805I max maps to about 2.88 V and
  D6505I max maps to about 1.44 V. Selected blue diode `PLT5 450GB` has no monitor
  photodiode, so `MPD_RAW4` / `MPD4` is spare/open for that source.
- **USB programming/control** — J1 is CP2102N USB-UART; J2 is ESP32-S3 native USB on
  GPIO19/GPIO20. Both connectors use copied-sheet discrete ESD clamps and VBUS
  isolation. `check_usb_vbus_interface.py` enforces the schematic topology,
  while the PCB checker enforces USB route length/skew/layer/width policy.
- **ESP32 EN/BOOT** — EN has 10 k pull-up + 1 uF POR/reset-delay cap + reset
  button; GPIO0/BOOT has 10 k pull-up + 1 uF cap + local PROG button.

**Still verify (firmware side):** U14 straps `RANGE` low for the base AD7606 **±5 V**
input range, `REF_SELECT` high for the internal reference, and `OS0..2` low for no
oversampling. Confirm ESP32 timing, serial readback mode, and scale conversion before
trusting bench readings; keep per-laser current ≲ 250 mA so `I·10Ω` stays inside the
ESP32 ADC window.

The generator emits globally unique schematic references before KiCad netlist export. Do not
reintroduce repeated sheet-local designators; `circuit_designators.py` is the translation layer
between readable logical route names and physical component references.

## Layout notes

- The 4 **SFH2201 PDs sit on the optical (left) board edge** so each laser beam reaches its
  detector; keep the OPA380 −IN summing node tiny and guarded, directly behind the PD.
- Star ground: keep laser-driver switching return and ESP32 digital ground off the analog TIA
  return; separate trace for the laser-driver returns back to the common entry.
- Keep Q1–Q4 drain traces (`LASER_Nx`) short and direct to `LD1..LD4`, away from TIA inputs.
- Keep `MPD_RAW1..4` and `MPD_BIAS` away from laser cathode switching/current traces;
  place the 240 ohm sense resistors, INA4180, LM4040, bias sink, and ADC filters close
  near the direct laser monitor inputs or quiet ADC entry path.
- If firmware needs AD7606 oversampling, change the U14 `OS0..2` straps intentionally;
  the current schematic ties them low for no oversampling.
- ISENSE headroom: I_laser·10Ω must stay inside the ESP32 ADC range (≈0–3.1 V with 11 dB
  atten) — keep per-channel current ≲ 250 mA, or drop R_sense on a high-current channel.
- **ESP32-S3 antenna keep-out**: no copper pour / parts in the module antenna zone (toward the
  board edge).

## Review gate

Run the available local gate after any generated schematic, PCB, checker, or
source-note change:

```bash
python3 circuits/run_laser_controller_review.py
```

For first-article or production release, use release mode:

```bash
python3 circuits/run_laser_controller_review.py --release
```

In this environment, release mode is expected to fail while
`check_laser_controller_release_readiness.py` still reports deferred
first-article/production blockers. That failure is intentional: the current
JLCPCB order package can be ready while bench-use or production release remains
blocked by missing measured calibration, firmware, thermal, protection,
procurement, or bring-up evidence. Do not clear the blocker registry until the
corresponding physical/source signoffs are recorded.

See `PCB_LAYOUT.md` for the full placement + routing/Gerber workflow.

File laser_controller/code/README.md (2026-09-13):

# Vivonics Laser-Controller Bring-Up Firmware

ESP32-S3 firmware for the fabricated four-laser/four-TIA controller. The normal
and board-validation profiles are measurement-only and expose no laser command
surface. A separately built local laser-test profile supports deliberate
first-article output tests over USB serial. The dashboard profile adds the
access-controller web foundation, AP/STA Wi-Fi, real-time AD7606/current/monitor
telemetry, remote first-article controls, and rollback-protected OTA. At
application entry every profile
configures GPIO10/11/12/16 low before ADC initialization, reads all four
AD7606-4 channels through DOUTA, and latches BUSY/SPI/timing or telemetry
failures into a laser-off state. The dashboard profile reports scheduling
deadline overruns instead of latching them because Wi-Fi and HTTP execution is
nondeterministic; BUSY/SPI and telemetry-read failures still latch All-Off. The
PCB's analog command-limit pulldowns—not
application firmware—provide the safe command state while the ESP32-S3 is held
in reset or is still in ROM/bootloader execution.

## Evidence boundary

- Implemented: safe boot GPIO, AD7606 reset/conversion sequencing with a latched
  BUSY rising edge, bounded BUSY fall timeout, mode-1 one-lane SPI, 64-clock
  V1–V4 decode, signed scaling, metadata/counters, and latched safety state.
- Laser-test profile implemented: local `STATUS`, `OFF`, bounded `PULSE`, and
  latched `ON` commands; every validated combination of the four wavelengths;
  10 kHz PWM below full command and a probeable steady GPIO high at `1000`
  permille; current-sense and monitor-PD telemetry.
- Dashboard profile implemented: professional responsive UI, 50 Hz telemetry,
  discovery/health/log/network APIs, the same safety-gated output state machine,
  WPA2 provisioning AP, saved station credentials, dual 2 MiB OTA slots, output
  inhibit during OTA, and delayed image-valid marking for rollback.
- Host verified: decoder boundary vectors, 100,000 deterministic round trips,
  safety transitions, and every defined fault latch.
- Target-build verified: the complete ESP32-S3 flash set was built twice from
  clean state and matched byte-for-byte. See
  [`BUILD_VERIFICATION_2026-07-12.md`](BUILD_VERIFICATION_2026-07-12.md).
- First-article observed: 5.2 V/3.3 V power and AD7606 reference rails, repeatable
  CONVST/BUSY activity, active DOUTA/DOUTB in the isolated diagnostic, 239
  consecutive four-channel board-validation samples without a firmware fault,
  and initial IR/green emission/current telemetry under the laser-test profile.
  See the parent repo's
  [first-article record](https://github.com/physiii/vivonics/blob/main/bench-output/laser-controller-first-article-2026-07-20.json).
- Dashboard/OTA observed on 2026-07-21: version `0.3.2-dashboard` running valid
  from `ota_1`, zero firmware faults, advancing 50 Hz AD7606 samples, responsive
  desktop/mobile layouts with no browser errors, simultaneous IR + Green
  control followed by verified All-Off, and unequal IR/Green duties of 70%/40%
  accepted and reported independently. IR current sense tracked the command at
  `365 mV`/approximately `36.5 mA` at 100% and `246 mV`/approximately `24.6 mA`
  at 70%. Green emitted under command but its current-sense and all equipped
  source-monitor ADC readings were `0`; those hardware sensing paths remain
  unresolved and are shown as degraded rather than hidden or simulated.
  The outputs-off `SENSETEST` subsequently produced a repeatable `45..50 mV`
  weak-pull response on all eight ESP32 sensing inputs across five runs. This
  proves the ADC inputs respond and rules out an obvious floating MCU-side path;
  the Green-current and common source-monitor faults are upstream analog issues.
- Dashboard safety follow-up observed on 2026-07-26: an acquisition/control-loop
  stall left the last active snapshot visible and prevented queued All-Off
  commands from being consumed. Version `0.3.3-dashboard` adds an independent,
  higher-priority output watchdog that reboots into safe-low GPIO state whenever
  an active snapshot is more than `500 ms` stale. The host boundary tests,
  pinned ESP-IDF build, rollback-protected OTA, advancing live samples, and
  outputs-off desktop/mobile smoke passed. The expired-watchdog reboot branch
  has not yet been deliberately fault-injected on the assembled board.
- Not yet verified: absolute ADC accuracy and channel order against known
  external inputs, calibrated optical power or source-monitor slope, board
  temperature at sustained duty, or fail-shutoff behavior under real
  reset/brownout/power faults.
- Not implemented: production laser authorization/control, dual-DOUT acquisition
  in the main sampler, authenticated LAN control, signed OTA images, or
  production security provisioning.

The board-level acceptance procedure remains in the parent repo's
[`LASER_CONTROLLER.md`](https://github.com/physiii/vivonics/blob/main/docs/program/LASER_CONTROLLER.md).

## Host tests

```bash
laser_controller/code/run-host-tests.sh
```

## Reproducible ESP-IDF build

The build uses Espressif's official ESP-IDF `v5.5.4` multi-architecture image,
pinned by OCI index digest. Both application and bootloader compile dates are
disabled so clean builds are byte-reproducible.

```bash
laser_controller/code/build-container.sh
```

Expected flash artifacts are written under `laser_controller/code/build/`.
Do not flash or connect lasers until the incoming-inspection and current-limited
power-up procedure in the master report is complete.

## Board-validation logging profile

The default build disables sample logging so synchronous UART output cannot hide
a missed 1 ms deadline. The injection fixture instead uses a separate 50 sample/s
profile that logs every sample and retains the same timing-fault latch:

```bash
laser_controller/code/build-validation-container.sh
```

Its artifacts and independent `sdkconfig.validation` are written under
`build-validation/`. Record that binary's hash with every calibration log; do
not substitute it for the byte-reproducible default artifact documented above.

## Local laser-output test profile

The normal and board-validation profiles keep all laser outputs inhibited. A
separate first-article profile adds a local UART test surface for staged optical
bring-up:

```bash
laser_controller/code/build-laser-test-container.sh
```

The artifacts are written under `build-laser-test/`. The profile accepts
`STATUS`, `OFF`, `SENSETEST`, `ON <target> <duty_permille>`, and
`PULSE <target> <duty_permille> <duration_ms>`. A target is any canonical
underscore-separated combination in IR, RED, GREEN, BLUE order, or `ALL`;
examples are `IR_GREEN`, `RED_BLUE`, and `IR_RED_GREEN_BLUE`. `ON` keeps the
selected channels active until `OFF`, reset, overcurrent, or an ADC/telemetry
fault. `PULSE` applies them for `20..900 ms`. Both accept `1..1000` permille
only when the AD7606 is ready and no fault is latched. A valid command received
on native USB-Serial/JTAG is the test-profile arm request; the `FACT` button is
not required. This profile is for controlled first-article work; it is not a
production authorization or control interface.
At `1000` permille the selected command pin is driven as a steady 3.3 V GPIO
level so it can be checked with a DC probe. Settings below `1000` use the
10 kHz LEDC PWM path and appear as a waveform at the corresponding duty cycle.
Each sample log includes calibrated `I`/`M` millivolts and the corresponding
uncalibrated `IRAW`/`MRAW` ADC counts so a zero-millivolt observation can be
distinguished from a disconnected input or a calibration-floor effect.

`SENSETEST` is accepted only while every output is off and the controller is
fault-free. It sequentially samples ISENSE1–4 and MPD1–4 while each ESP32 input
is floating, weakly pulled up, and weakly pulled down, then restores the input
to floating. A floating board path follows both weak pulls; a connected,
low-impedance zero-volt source remains near zero. The command never enables a
laser and logs `SENSE_PIN` records over native USB-Serial/JTAG for first-article
fault isolation.

## Laser dashboard and OTA profile

Build the web-enabled first-article image with the pinned ESP-IDF container:

```bash
laser_controller/code/build-dashboard-container.sh
```

The profile is versioned independently and writes artifacts under
`build-dashboard/`. Its custom 16 MiB layout contains `ota_0` and `ota_1`, each
2 MiB, plus NVS, PHY, and OTA-selection data. A full initial flash needs the
bootloader at `0x0`, partition table at `0x8000`, initial OTA data at `0xe000`,
and application at `0x10000`. The fabricated board can be programmed without
holding `FACT`: use the CP2102N auto-reset USB connector when available, or the
ESP32-S3 built-in USB-JTAG interface. Subsequent releases upload only
`vivonics_laser_controller.bin` through the System tab or
`POST /api/ota/upload`.

On every boot the controller advertises `VIVONICS-LASER-<MAC>` with WPA2 key
`vivonics` at `http://192.168.4.1/`. Use the Network tab to save the bench Wi-Fi
credentials; the AP remains available while the station interface connects.
The assigned station address appears in the Network/System views and
`GET /api/state`. Credentials are stored in NVS and are not embedded in the
firmware image.

The main HTTP surface is:

- `GET /api/health`, `/api/state`, `/api/telemetry`, `/api/discovery`, and
  `/api/logs`
- `POST /api/lasers` and `/api/lasers/off`
- `POST /api/diagnostics/sensing-pins` while fault-free and All-Off; results
  appear as `SENSE_PIN` entries in `GET /api/logs`. The Dashboard's driver
  telemetry card runs this electrical-only test and renders all eight raw
  floating/pull-up/pull-down results without energizing a laser.
- `GET /api/wifi/list` and `/api/wifi/scan`; `POST /api/wifi`
- `POST /api/ota/upload` with a raw ESP-IDF application binary

Run the deterministic local UI test with `tests/dashboard-ui-smoke.js`. Run the
live-device test with `tests/dashboard-live-smoke.js <base-url>`; add
`--exercise-multi` only at a controlled optical bench. The multi-output test
uses the UI to add IR and Green concurrently, removes IR without disturbing
Green, and then forces All-Off. Every live test checks desktop/mobile rendering
and fails on browser console errors, missing telemetry, faults, or viewport
overflow.

`POST /api/lasers` remains compatible with a shared-duty command such as
`{"target":"IR_GREEN","dutyPermille":1000}`. Independent per-source duty uses
`{"channels":[{"target":"IR","dutyPermille":700},{"target":"GREEN","dutyPermille":400}]}`.
The state and telemetry responses return the active channel mask and the duty
assigned to each channel.

## Safety behavior and sensing limits

Firmware-enforced output inhibition includes safe-low boot GPIOs, a valid ADC
startup sample, fault-free arm/run transitions, input validation, PWM register
or GPIO-pad readback, AD7606 BUSY/SPI checks, telemetry-ADC read checks, and
per-channel hard current ceilings. The dashboard profile also runs an
independent output watchdog: while any channel is active, a control snapshot
older than `500 ms` forces a software reboot so boot-safe GPIO initialization
removes the output even if the acquisition task can no longer consume its
command queue. The current-sense ceilings are IR `450 mV`
(approximately `45 mA`), Red `300 mV` (`30 mA`), Green `850 mV` (`85 mA`), and
Blue `1150 mV` (`115 mA`). Exceeding one forces all channels off and latches a
reset-required fault. OTA start also commands All-Off.

An active channel with zero current-sense or equipped source-monitor response
sets `sensingDegraded`, makes `/api/health` unhealthy, and produces an explicit
dashboard warning. It does **not** currently latch a shutdown fault. Therefore
the Green overcurrent gate cannot be credited while its current-sense path is
reading zero, and the source monitors cannot be credited while their paths are
reading zero. There is no physical door/key/E-stop interlock and no network
command-heartbeat timeout in this bench profile.

This is a first-article operator surface, not a production safety controller.
LAN requests are currently unauthenticated, OTA images are not signed, and the
documented AP2112 no-RF thermal acceptance does not cover sustained Wi-Fi.
Measure +3V3 current and U11 temperature under the dashboard workload or change
the regulator before treating continuous wireless operation as released.

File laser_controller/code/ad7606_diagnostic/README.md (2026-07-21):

# AD7606-4 isolated hardware diagnostic

This temporary first-article image distinguishes a missing AD7606-4 BUSY pulse
from an ESP32 polling miss and tests serial readback without trusting BUSY. It
does not provide a laser arm path: GPIO10, GPIO11, GPIO12, and GPIO16 are forced
low continuously.

The image performs three bounded phases with the ESP32 internal pulls floating,
up, and down on BUSY/DOUTA/DOUTB. Each phase:

- applies a 10 us active-high RESET followed by 100 us recovery;
- generates eight 10 us-low CONVST pulses;
- counts BUSY transitions using a GPIO any-edge interrupt;
- samples BUSY immediately, 1 us, and 3 us after CONVST rises;
- waits 20 us, then reads two 16-bit channels from each DOUT line using 32 slow
  bit-banged serial clocks.

It then generates a conversion every 100 ms indefinitely for scope triggering.

Build on an ESP-IDF host:

```bash
source "$HOME/esp/esp-idf/export.sh"
cd firmware/ad7606_diagnostic
idf.py set-target esp32s3
idf.py build
```

Flash on the office bench host:

```bash
export ESPTOOL_CFGFILE="$PWD/esptool.cfg"
idf.py -p /dev/ttyUSB0 flash
```

Interpretation:

- BUSY edges prove conversion signaling even if polling missed it.
- BUSY following the ESP32 pull-up indicates an undriven/open BUSY connection.
- Read data invariant across DOUT pull states indicates the ADC is driving it.
- Read data following pull state indicates DOUT is undriven, narrowing the fault
  to ADC power/configuration, CS/SCLK connectivity, package soldering, or U14.

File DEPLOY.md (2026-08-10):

# Vivonics Pi Bench Deployment

The bench repo is checked out as the `bench/` submodule inside the parent
Vivonics checkout. The Raspberry Pi service can also be deployed as a
standalone working tree on the Pi; the existing deployment target remains
`/home/andy/vivonics/pi`.

## Current bench target

- Host: `raspberrypi.local`
- Current IPv4s observed on the Pi: `192.168.1.174`, `192.168.1.176`
- User used by local scripts: `andy`
- Service port: `8090`
- Expected path in the parent Vivonics checkout: `/home/andy/vivonics/pi`

## Deploy from this workstation

From this repo:

```bash
scripts/deploy_remote.sh andy@raspberrypi.local /home/andy/vivonics/pi
```

The deploy script rsyncs this repo into the target path, installs Python
dependencies in a repo-local `.venv`, installs/restarts the user systemd
service, and prints the service status plus `/status` response.

## Manual Pi install

On the Pi:

```bash
cd /home/andy/vivonics/pi
sudo raspi-config nonint do_i2c 0
./install.sh
curl http://127.0.0.1:8090/status
curl http://127.0.0.1:8090/sensors
/usr/sbin/i2cdetect -y 1
```

The bench service installed by `install.sh` defaults to:

```text
VIVONICS_LIGHT_DRIVER=both
VIVONICS_RED_LASER_GPIO=15
VIVONICS_GREEN_LASER_GPIO=24
VIVONICS_INFRARED_LASER_GPIO=23
VIVONICS_BLUE_LASER_GPIO=14
VIVONICS_LASER_ACTIVE_HIGH=1
```

That maps red laser enable to physical pin `10`, green to physical pin `18`,
infrared to physical pin `16`, and blue to physical pin `8`. The laser control
is active-high by default: `Off` drives the GPIO pins low, and an active channel
is driven high. Treat the GPIO pins as logic outputs into transistor or MOSFET
switches; do not sink laser current directly through the Pi.

`sudo raspi-config nonint do_i2c 0` is intentionally not run by the deploy
script because it may require an operator password and should only be changed
when the Pi wiring is in a known state.

## Claim boundary

This repo only owns shared-optical-metrology and operator-screen bench
instrumentation: HDMI projector frames, IMX477 capture, auxiliary I2C sensor
snapshots, and smoke-test measurement scripts.
It does not make evidence-grade bacteriorhodopsin, purple-membrane, or
weight-plane claims by itself.

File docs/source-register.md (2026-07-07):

# Bench Laser Controller Source Register

Generated/updated: 2026-07-07.

This register ties the generated KiCad design to primary manufacturer documents,
local library evidence, and automated checks. It is not a release waiver. GUI ERC,
PCB DRC with refilled zones and schematic parity, and manufacturing package quote
review can block fabrication ordering. Remaining first-article/release-readiness
items block bench-use or production release until measured evidence exists.

## Standards / Manufacturing Capability

| Source | Scope | Captured Rule / Use | Confidence |
|---|---|---|---|
| JLCPCB PCB capabilities, `https://jlcpcb.com/capabilities/pcb-capabilities` | Prototype PCB trace/space and stackup manufacturability. | Project routing rules reserve 0.20 mm minimum signal traces, 0.50-0.80 mm power/current traces, 0.45/0.20 mm low-current GND dogbone vias, and 0.60/0.30 mm power/current vias; these are intentionally above common low-cost capability values. The current PCB artifact has 1611 routed segments and 236 vias, so final DRC/manufacturing settings still need explicit board setup review before fabrication. | High for capability direction; exact order tier must be confirmed at fabrication quote. |
| JLCPCB PCB assembly capabilities, `https://jlcpcb.com/capabilities/pcb-assembly-capabilities` | Bench prototype PCB assembly tier. | Selected order target is JLCPCB Economic PCBA for a 4-layer, 1.6 mm rigid FR-4 standard-stackup board with top-side SMT assembly plus JLC-quoted THT connector assembly where accepted. The generated assembly files are `circuits/laser_controller_bom_jlcpcb.csv` and `circuits/fab/laser_controller_pos.csv`; J1/J2, J5/J6, and J7 are included in the JLCPCB BOM/CPL, while LD1-LD4 remain hand-installed optical parts. The JLC package gate now includes the U1-U4/RV1-RV8 physical orientation gate because the 2026-07-07 JLCPCB preview exposed a mirrored embedded-footprint failure that BOM/CPL shape checks alone did not catch. Move to Standard PCBA only if quote review rejects the economic tier, connector source fit, THT assembly request, or extended-part setup. | Medium-high; JLCPCB quote review wins over this planning target. |
| JLCPCB via guidance, `https://jlcpcb.com/blog/pcb-via-design-best-practices` | Mechanical drill/via sizing. | Via classes include 0.60 mm diameter / 0.30 mm drill for low-current signal transitions and 1.00/0.50 mm or 1.20/0.60 mm vias for power/current paths. The current PCB has 236 board-level vias; quote capability page wins over advisory guidance. | Medium; blog is not a contract, quote capability page wins. |
| KiCad stock footprint libraries under `/usr/share/kicad/footprints` | Footprint pad geometry and local footprint names. | PCB generator embeds footprints from the installed KiCad library and assigns nets from exported schematic netlist. | Medium; footprint geometry is checked locally but not a substitute for manufacturer land-pattern review. |
| `circuits/check_laser_controller_netlist.py` | Schematic netlist guardrails. | Exact pin/package/value/footprint/MPN/LCSC checks, exact rail membership, exact USB/laser/TIA/MPD/AD7606 nets, direct TO-can laser model pin checks, fail-closed multi-pin net coverage, single-node no-connect allowlist coverage, physical pin uniqueness. | High for generated schematic consistency. |
| `circuits/check_laser_diode_footprints.py` | Direct laser-can footprint/pinout guardrail. | Verifies selected LD1-LD4 MPN/value/footprint identities, schematic pin nets, current PCB pad nets, LD4 case no-connect, `MPD_RAW4` spare/open membership, and installed KiCad TO18/TO56 through-hole pad geometry. | High for source-to-schematic-to-current-PCB pin numbering consistency; physical diode orientation and optical/mechanical inspection remain manual. |
| `circuits/check_orientation_polarity_pcb.py` | Physical pad-order orientation/polarity guardrail. | Verifies U1-U4 OPA380AID SOIC-8 physical local pad order, intentional 180-degree board placement, TI datasheet pin nets, and RV1-RV8 Bourns 3224W physical wiper/end-terminal geometry and nets. This gate exists because the 2026-07-07 JLCPCB preview showed that numeric pad-net checks alone can miss a mirrored embedded footprint. | High for the repaired OPA380/Bourns mirror-risk parts; not a substitute for JLCPCB assembly-viewer review after upload or future-package substitutions. |
| `circuits/check_schematic_hierarchy_labels.py` | Schematic hierarchy and label guardrails. | Fails if root sheet pins or pin directions differ from child hierarchical labels and label shapes, if a child sheet gains an accidental global label, if root global labels differ from the explicit board-level whitelist, or if generated sheet annotation text leaks stale local generator designators such as pre-annotation USB/power header names. Current generated root includes the AD7606 serial/control interface alongside the laser, TIA, MPD, power, and MCU sheet pins. | High for generated sheet-interface and label-discipline consistency; not a substitute for GUI ERC. |
| `circuits/check_laser_controller_sources.py` | Source and net/pin-intent coverage guardrails. | Verifies every exported MPN/LCSC token appears in the source register or part notes, required source/risk phrases are present, every exported net has a specific electrical-intent mapping in the generated full net/pin inventory, every exported component pin has a component-pin-level role, and active documentation uses the copied MCU-sheet CP2102N/Mini-B/discrete-ESD/AP2112/OR-ing designators rather than stale local generator names. | High for source/register coverage and net/pin-intent completeness; external document presence is covered separately by `check_source_documents.py`. |
| `circuits/check_part_notes_completeness.py` | Part-note completeness guardrail. | Fails if any critical part note exists but drops the package pinout, layout-sensitive design decision, release-risk text, or checker-evidence phrases needed for ESP32, OPA380, TLV9001, AP2112, AD7606, AO3400A, SFH2201, SS14, Mini-B connectors, Bourns 3224, PLT5-style direct laser footprints, laser pin-code compatibility, or passive BOM evidence. | High for keeping datasheet capture notes auditable; still not a replacement for final latest-revision datasheet and procurement review. |
| `circuits/check_source_documents.py` | Source-document evidence guardrail. | Hard-fails missing required primary datasheet/manufacturer URLs that are probeable from this environment and required local artifacts such as the access-controller ESP32-S3 source sheet, local OPA380 datasheet copy, and package-sensitive KiCad footprints. Reports secondary/distributor evidence, known source conflicts, and source URLs that still need release-time manual latest-revision/procurement verification as warnings. | High for missing-evidence detection; not a substitute for revision-control review of latest datasheet versions or final procurement AVL lock. |
| `circuits/check_usb_vbus_interface.py` | USB/VBUS entry guardrail. | Verifies J1 USB-UART, J2 native ESP32 USB, CP2102N QFN28 pins 4/5/8, ESP32-S3 module pins 13/14, Mini-B pins 1-6, discrete ESD clamps, 1N5819HW VBUS isolation, D5 +5 V OR-ing, CP2102N VBUS 22.1 k / 47.5 k divider plus C45, RST pull-up, UART, EN/BOOT auto-reset, and ID no-connects. The `connector-source-match` policy passes when J1/J2 use stocked Mini-B `920-462A2021S10101` / LCSC `C46391` metadata on the copied Mini-B placement footprint. | High for schematic topology and connector-source alignment; final USB routing, ESD placement, board-edge orientation, and quote acceptance still need layout/procurement review. |
| `circuits/check_esp32_reset_boot_controls.py` | ESP32 reset/boot/factory guardrail. | Verifies U9/U10/Q5/Q6/SW1-SW3, EN 10 k / 1 uF / RESET, GPIO0 BOOT 10 k / 1 uF / PROG, GPIO1 FACT, CP2102N QFN28 DTR/RTS transistor auto-reset nets, CP2102N RST/SUSPEND pulls, IO13/IO14 pulls, and shared +3V3/GND support nodes. | High for schematic topology and copied MCU-sheet pinout preservation; still needs bench flashing/reset validation and final button placement/mechanical review. |
| `circuits/check_laser_controller_pcb.py` | PCB pad/net/route guardrails. | Checks footprint pad-net assignment, declared layers/classes, pad bounds, routed-copper board bounds, unnetted pad whitelist, proximity rules, net-class copper clearance including trace-to-pad and via-to-pad spacing, duplicate via stacks, dangling copper endpoints/vias, route-layer policy, route-width policy, sensitive local-route length policy, non-power via-count policy, critical local-route connectivity, and generated-board USB D+/D- route length/skew/via/layer/width limits. Current board evidence passes the default custom PCB gate with 119 named PCB nets, 181 physical footprints, 1611 routed copper segments, 236 vias, four board-level zones, and one footprint-internal ESP32 antenna keepout zone. | High for generated PCB consistency; not full DRC. |
| `circuits/check_schematic_pcb_parity.py` | Headless schematic-to-PCB pad-net parity guardrail. | Compares the exported schematic netlist against the current hand-routed PCB footprint set, footprint names, real net table, pad nets, and unconnected pins. Current evidence passes with 181 schematic footprints matching 181 PCB footprints and 110 real PCB nets matching exported schematic pad nets, with unconnected pins left unnetted. | High for stale-footprint/stale-pad-net detection; not native KiCad ERC, native DRC, zone refill proof, or manufacturer clearance checking. |
| `circuits/check_jlcpcb_order_package.py` | JLCPCB prototype order-package checker. | Verifies Gerber/drill zip contents, BOM/CPL designator match, CPL coordinates/rotations, J1/J2 stocked Mini-B metadata, J5/J6 THT assembly rows, J7 C192300 SMD header metadata, full-procurement split between JLCPCB assembly and hand-installed optical cans, required board labels, flat archive freshness, top-side TIA SMT placement, and the U1-U4/RV1-RV8 physical orientation gate. | High for package artifact consistency and the repaired mirror-risk parts; not a substitute for JLCPCB quote acceptance, assembly-viewer approval, or production release. |
| `circuits/check_laser_controller_release_gate.py` | Generated-copper fabrication gate. | Fails on split multi-pad nets, rail/zone pending nets, laser cathode/anode current copper below the project width/length/via limits, or missing distinct high-current GND vias for the 10 ohm laser sense returns. Current board passes this generated-copper gate for explicit multi-pad connectivity, laser cathode/anode current copper, and laser sense-return high-current GND vias. GUI ERC, native KiCad DRC/parity, thermal acceptance, and bench measurements remain separate release gates. | High for project-specific generated-copper checks. |
| `circuits/check_layout_review_geometry.py` | Focused layout-geometry release review. | Blocks while high-risk physical layout distances exceed project targets for AP632 buck input/output loops, native USB ESD placement, OPA380 summing-node loops, monitor-PD raw paths, or laser-current sense loops. Current board evidence passes all 15 focused layout-distance checks. | High for layout-review triage; not a replacement for KiCad DRC, impedance/current/thermal simulation, or bench noise/ripple measurement. |
| `circuits/check_kicad_pcbnew_drc_report.py` | Headless native Pcbnew DRC report. | Uses system Python's KiCad `pcbnew` module to refill zones in memory and write `circuits/review/generated/laser_controller_pcbnew_drc_report.rpt`. Current report passes with zero unconnected pads and zero footprint errors; the only native Pcbnew findings are 4 documented `courtyards_overlap` warning-level findings. | High for native PCB-rule evidence from KiCad 7.0.11 Pcbnew; not schematic ERC, native schematic-parity DRC, JLCPCB quote acceptance, or a waiver for the courtyard-overlap warnings. |
| `circuits/check_courtyard_overlap_triage.py` | Native courtyard-overlap triage. | Reads the headless Pcbnew DRC report and compares the warning pairs against current F.Fab/F.CrtYd geometry. Current triage writes `circuits/review/generated/laser_controller_courtyard_overlap_triage.md` and reports 4 native courtyard-overlap pairs: 0 F.Fab/body-box overlaps, 4 courtyard-only overlaps, and 4 explicit assembly-clearance waivers. | High for separating likely physical body interference from courtyard-only assembly-clearance warnings; not an automated reroute, physical fit waiver, GUI ERC, or manufacturer assembly acceptance. |
| `circuits/check_power_thermal_budget.py` | AP2112 3V3 rail thermal policy. | Passes the bench USB/UART/no-RF assumption only when the AP2112 SOT25 5 V to 3.3 V dissipation stays under the target junction limit; sustained Wi-Fi/BLE scenarios are expected to fail unless the regulator is changed or duty-cycle/thermal proof is added. | High for first-order AP2112 thermal math; final board temperature still needs measurement. |
| `circuits/check_power_bringup_template.py` | First-article power/input bring-up measurement-template guardrail. | Verifies `circuits/review/calibration/first_article_power_bringup_template.csv` includes rows for J5/VIN24 bench input, the unresolved VIN24 production-protection gap, U15 `/POWER_IO/BUCK_5V`, D5/D6 post-OR `+5V`, U16 `LASER_V+`, and U11 `+3V3` AP2112 thermal/current measurements. | High for preventing skipped power bring-up measurements; not production input protection, ripple/stability proof, measured thermal data, or sustained wireless release. |
| `circuits/review/signoff/2026-07-05-ap2112-first-article-signoff.md` | AP2112 first-article no-RF operating signoff. | Accepts the current AP2112K-3.3 rail only for USB/UART bench firmware with ESP32 Wi-Fi/BLE disabled, continuous +3V3 current no higher than 120 mA, no added 3.3 V loads without rerunning the thermal budget, and required AP2112 package-temperature/+3V3-current measurement during first bring-up. | Allows controlled first-article bring-up; sustained Wi-Fi/BLE, production regulator decision, and measured thermal evidence remain open. |
| `circuits/review/signoff/2026-07-05-ap2112-category-review.md` | Severity-ranked AP2112 +3V3 regulator category review artifact. | Records that the AP2112 rail is rank 3 high, lists the no-RF bench-only conditions, summarizes the passing bench thermal policy and expected-fail Wi-Fi/BLE policies, and maps the `AP2112_BENCH_MEASUREMENT_OR_REGULATOR_CHANGE` ledger rows to the exact evidence needed before closure. | High for order-readiness traceability; does not close measured AP2112 temperature/current, sustained wireless operation, regulator replacement, or production regulator release. |
| `circuits/check_buck_input_power_budget.py` | VIN_24V and AP63205/AP63200 buck policy. | Verifies AP63205/AP63200 pinout, R61/R62 feedback math, bootstrap/inductor component identity, 24 V connector input current, estimated buck inductor peak/RMS current, and AP632 datasheet component recommendations. The selected-diode 9.3 V max-current reference, the all-channel per-channel analog-limit case, and `datasheet-recommended-components` pass after moving C64-C65/C67-C68 to 2x22 uF 25 V ceramics per rail. | High for first-order input/buck current and schematic component checks; output ripple, stability, thermal behavior, hot-plug transients, and final layout still need bench validation. |
| `circuits/check_ap6320x_package_pcb.py` | AP63205/AP63200 package and PCB pad-net guardrail. | Verifies U15/U16 MPN/value/LCSC/TSOT-23-6 identity, datasheet-derived `FB/EN/IN/GND/SW/BST` schematic nets, current PCB pad nets for U15/U16 plus local L/C/R support parts, the installed KiCad TSOT-23-6 pad geometry, and the local Open_Automation L1/L2 inductor footprint pad geometry. | High for source-to-schematic-to-current-PCB package pin agreement; not buck ripple, switch-loop layout, thermal behavior, transient response, or production input-protection proof. |
| `circuits/review/signoff/2026-07-05-ap632-first-article-buck-validation-signoff.md` | AP632 first-article buck validation signoff. | Requires J5-only 24.0 V input with external current limit no higher than 300 mA, RJ45 power disabled, no hot-plug, `/POWER_IO/BUCK_5V`, post-OR `+5V`, and `LASER_V+` verification before enabling loads, `LASER_V+` treated as a 9.3 V-class rail, startup overshoot/ripple/load-step capture, U15/U16/L1/L2/D6/C64-C65/C67-C68 temperature measurement, and rerunning the buck budget before rail/input/load/capacitor/inductor changes. | Allows controlled first-article buck bring-up; production input protection, adapter/RJ45 harness rating, reverse/TVS protection, hot-plug behavior, and measured ripple/transient/stability/temperature data remain open. |
| `circuits/check_vin24_input_protection.py` | VIN_24V bench topology and production input-protection policy. | Verifies J5/J6 component identity and pin mapping, J5 center pin and J6 pins 4/5 on `VIN_24V`, J5 pins 2/3 and J6 pins 7/8/9/11 on GND, U15/U16 IN/EN on `VIN_24V`, and the input-cap/RJ45 LED/contact topology. `production-protection` intentionally fails because the connector pins and buck IN pins are on the same net with no fuse/PTC/TVS/reverse-protection/eFuse/hot-swap component, while 24 V nominal already uses 80 percent of the J5 voltage rating and 75 percent of the AP632 input maximum before transients. | High for current schematic topology and missing-protection detection; production still needs selected adapter, harness rating, surge/reverse protection design, and bench transient measurements. |
| `circuits/review/signoff/2026-07-05-vin24-bench-input-signoff.md` | VIN24 first-article bench input signoff artifact. | Defines the accepted bench-only input configuration: J5 barrel input, 24.0 V, external current limit no higher than 300 mA, RJ45 power disabled, verified center-positive polarity, no hot-plug, and no reverse connection. | Allows controlled first-article bench bring-up without claiming production input protection; onboard fuse/PTC/TVS/reverse/eFuse design and bench ripple/transient/temperature measurements remain open. |
| `circuits/review/signoff/2026-07-05-vin24-category-review.md` | Severity-ranked VIN24/buck category review artifact. | Records that VIN24 input and buck bring-up are rank 1 critical, lists the bench-only conditions that make first-article ordering acceptable, records the expected-fail production-protection state, and maps the three `VIN24_INPUT_PROTECTION_AND_BUCK_LAYOUT` ledger rows to the exact evidence needed before closure. | High for order-readiness traceability; does not close first-power measurements, buck ripple/transient/temperature data, or production input-protection design. |
| `circuits/check_laser_driver_control_loop.py` | TLV9001/AO3400A laser-driver control-loop policy. | Verifies each PWM divider/filter node feeds TLV9001 IN+, each AO3400A source/sense node feeds TLV9001 IN-, each TLV9001 OUT drives the AO3400A gate through 1 kOhm, each drain lands on the correct direct-laser cathode net, and the +5 V/GND local support nodes are present. The selected max-current checks pass TLV9001 input range and AO3400A gate-drive margin for IR/red/green/blue, and `hardware-clamp-gate-margin` now passes as the per-channel analog-limit compatibility policy. | High for schematic topology and first-order gate-drive range; loop stability, transient behavior, current calibration, diode limits, optical safety, and board temperature still need measurement. |
| `circuits/check_laser_driver_package_pcb.py` | TLV9001/AO3400A laser-driver package and PCB pad-net guardrail. | Verifies U5-U8 TLV9001IDBVR DBV/SOT-23-5 pin nets, Q1-Q4 AO3400A SOT-23 gate/source/drain nets, local 1 k gate resistors, 10 ohm 2512 sense resistors, 1 k ISENSE taps, 10 k/per-channel PWM command dividers, 1 uF PWM filters, 10 pF compensation capacitors, 100 nF TLV decoupling capacitors, exact `PWMx`/`ISENSEx`/`LASER_Nx`/LOUT/FB/gate net membership, current PCB pad nets, and installed KiCad SOT-23-5/SOT-23/2512/0603/0402/0603-cap pad geometry. | High for source-to-schematic-to-current-PCB package pin agreement; not laser-current SOA, loop stability, optical safety, or routed-current copper proof. |
| `circuits/check_laser_current_budget.py` | Laser current-loop thermal policy. | Checks the per-channel PWM command limits, 10 ohm 2512 sense resistor power, AO3400A linear-pass dissipation, safe `LASER_V+` window, and selected LD1-LD4 diode current/Vf limits. It still shows that one common high `LASER_V+` rail is a bench convenience, not a production architecture. `selected-diodes-typ-9v3`, `selected-diodes-max-9v3`, and `selected-diodes-hardware-clamp-9v3` pass for the present 9.3 V common-rail reference and per-channel analog limiters; the generic high-rail expected-fail policies remain as guardrails. | High for first-order current-loop math; duty cycle, optics safety, production driver architecture, and board temperature still need measurement. |
| `circuits/review/signoff/2026-07-05-laser-first-article-bringup-signoff.md` | Laser first-article bring-up signoff. | Requires appropriate wavelength-rated laser safety eyewear, an enclosed beam stop, received-can inspection against the 2026-07-04 MPN/footprint pin table, one-channel-at-a-time bring-up, minimum firmware duty/command start, firmware clamps at or below IR 38.0 mA, red 23.0 mA, green 76.2 mA, and blue 105.5 mA, shared `LASER_V+` verification, driver/sense-resistor temperature measurement, and external optical-power measurement. | Allows controlled first-article bring-up; optical safety, measured optical output, measured temperature, firmware clamp behavior, duty-cycle limits, and loop transient behavior remain open. |
| `circuits/review/signoff/2026-07-05-laser-category-review.md` | Severity-ranked laser current/thermal/safety category review artifact. | Records that laser bring-up is rank 2 critical, lists the one-channel-at-a-time bench-only conditions, summarizes the passing selected-diode current and direct footprint checks, and maps the `PER_DIODE_LASER_THERMAL_BUDGET` ledger rows to the exact evidence needed before closure. | High for order-readiness traceability; does not close received-can inspection, optical-output measurement, temperature data, firmware clamp behavior, or production laser release. |
| `circuits/check_laser_bringup_template.py` | First-article laser bring-up measurement-template guardrail. | Verifies `circuits/review/calibration/first_article_laser_bringup_template.csv` includes LD1-LD4 rows with the current nominal and tolerance-corner per-channel analog command limits, LASER_V+ check, wavelength-rated safety fixture, received-can pinout inspection, one-channel-at-a-time bring-up, measured current, driver/sense-resistor temperature, external optical power, and shutoff behavior fields. | High for preventing skipped laser safety/thermal measurements during first article; not measured optical output, measured temperature, firmware validation, or production laser release. |
| `circuits/check_monitor_pd_package_pcb.py` | INA4180/LM4040 monitor-PD package and PCB pad-net guardrail. | Verifies U12 INA4180A1IPWR PW TSSOP-14 pin nets, U13 LM4040C50IDBZR DBZ/SOT-23 pin nets, R41/C35/C36, four 240 ohm high-side monitor sense resistors, four 1 k / 100 nF ESP32 ADC filters, exact `MPD_RAWx`/`MPD_BIAS`/`MPD_AMPx`/`MPDx` net membership, current PCB pad nets, LD4 case no-connect, and installed KiCad TSSOP-14/SOT-23/0603/0402 pad geometry. | High for source-to-schematic-to-current-PCB package pin agreement; not optical calibration, APC safety, or production APC approval. |
| `circuits/check_laser_monitor_pd_budget.py` | Internal monitor-PD bias/ADC policy. | Checks the high-side monitor-PD front end and asserts the exported U12/U13/LD/ESP32 monitor netlist. For PLT5 520EB_P at `LASER_V+ = 10.5 V`, `MPD_RAWx -> 240R -> MPD_BIAS`, INA4180A1 gain 20, and LM4040C50 biasing give about 0.72 V at the ESP32 ADC for typical 150 uA monitor current, about 4.96 V monitor-PD reverse bias at typical current, and about 5.00 V dark/off reverse bias while the PLT5 datasheet monitor-current condition is `VRPD = 5 V`. The selected-laser typical and high-end monitor policies now fit the local 2.90 V ADC guard; D7805I 600 uA high-end monitor current maps to about 2.88 V. | High for first-order monitor-front-end math and schematic connectivity on compatible monitor-PD parts; not an optical calibration or APC waiver. PLT5 450GB has no monitor photodiode, so MPD4 is spare/open for the selected blue diode. |
| `circuits/review/signoff/2026-07-05-monitor-pd-first-article-calibration-signoff.md` | Monitor-PD first-article calibration signoff. | Requires LD1-LD3 external optical-meter calibration before MPD telemetry is used for APC, normalization, or safety behavior; records that LD4 PLT5 450GB has no monitor photodiode and `MPD_RAW4` / `MPD4` must remain spare/open; requires one-source-at-a-time bring-up, dark/off counts, response slope, saturation threshold, optical-power reading, and firmware fail-shutoff behavior. | Allows controlled first-article monitor-PD bring-up; measured calibration data, production APC, normalization, optical-safety release, and firmware implementation remain open. |
| `circuits/review/signoff/2026-07-05-monitor-pd-category-review.md` | Severity-ranked monitor-PD APC/calibration category review artifact. | Records that monitor-PD/APC calibration is rank 6 high, summarizes the passing INA4180/LM4040 package/pad-net, selected monitor-current ADC-headroom, signoff, and template checks, and maps the `MONITOR_PD_FRONTEND_RANGE_CALIBRATION` ledger rows to the exact evidence needed before closure. | High for order-readiness traceability; does not close measured LD1-LD3 optical calibration, MPD4 spare/open firmware behavior, production APC, normalization, or optical-safety release. |
| `circuits/check_optical_calibration_template.py` | First-article optical/readout calibration template guardrail. | Verifies `circuits/review/calibration/first_article_optical_calibration_template.csv` includes 12 required rows: LD1-LD4 monitor-PD handling, D1-D4 signal-PD/TIA calibration, and U14 V1-V4 AD7606 known-input readback. | High for preventing skipped channels in first-article data capture; not measured optical calibration, firmware validation, or production measurement release. |
| `circuits/check_ad7606_package_pcb.py` | AD7606-4 package and PCB pad-net guardrail. | Verifies U14 is AD7606BSTZ-4RL on the KiCad `LQFP-64_10x10mm_P0.5mm` footprint, all U14 schematic pin nets match the datasheet-derived serial/strap/reference/input map, C51-C60 AVCC/VDRIVE/REGCAP/reference capacitor identities and schematic/PCB pad nets match the intended rails/reference nodes, current PCB pad nets match the exported schematic, FRSTDATA pad 15 is intentionally unnetted, and the installed KiCad LQFP-64 pad geometry still has the expected 64 SMD pads at 0.5 mm pitch. | High for source-to-schematic-to-current-PCB package pin agreement; not analog accuracy, firmware proof, or board-level DRC. |
| `circuits/check_ad7606_interface_budget.py` | AD7606-4 firmware interface budget. | Verifies U14 is the AD7606BSTZ-4RL LQFP-64, the board is strapped for serial mode with `RANGE=0`, `OS[2:0]=000`, `DB15/BYTE_SEL=0`, internal reference, +5 V AVCC, +3V3 VDRIVE, two DOUT lines into the ESP32, and the default 10 MHz / 100 kSPS firmware timing budget. | High for schematic/firmware-contract consistency; firmware implementation, analog accuracy, and final PCB layout still need bench validation. |
| `circuits/check_firmware_validation_template.py` | First-article AD7606 firmware/readback validation-template guardrail. | Verifies `circuits/review/calibration/first_article_firmware_validation_template.csv` includes rows for scoped RESET/CONVST/BUSY/CS/SCLK timing, both DOUT lines, +/-5 V/no-oversampling scaling, VOUT1..4 channel order, and known-input count accuracy. | High for preventing skipped firmware validation evidence; not firmware implementation, scoped timing data, analog accuracy data, or production measurement release. |
| `circuits/review/signoff/2026-07-05-ad7606-first-article-readback-signoff.md` | AD7606 first-article firmware/readback signoff. | Requires SCLK at or below 10 MHz, 100 kSPS or lower, read-after-conversion firmware, RESET/CONVST/BUSY/CS timing validation, 32 SCLK edges per DOUT line, both ADC_MISO_A/ADC_MISO_B read, channel ordering for VOUT1..4, RANGE=0 +/-5 V scaling, OS[2:0]=000 no-oversampling, 16-bit twos-complement 152.59 uV/LSB scaling, and known-voltage or known-TIA-input readback before trusting bench ADC data. | Allows controlled first-article AD7606 firmware bring-up; firmware implementation, scoped timing, analog accuracy, known-input readback data, optical/TIA calibration, and production measurement release remain open. |
| `circuits/review/signoff/2026-07-05-ad7606-category-review.md` | Severity-ranked AD7606 firmware/readback category review artifact. | Records that AD7606 readback is rank 4 high, summarizes the passing package/pad-net, serial strap, timing-budget, signoff, and validation-template checks, and maps the `AD7606_SYSTEM_INTERFACE` ledger rows to the exact evidence needed before closure. | High for order-readiness traceability; does not close firmware implementation, scoped timing, live DOUT readback, known-input data, or production measurement release. |
| `circuits/check_tia_readout_budget.py` | SFH2201/OPA380 signal-PD TIA range policy. | Verifies each SFH2201 cathode is biased from +5 V, each anode goes to the OPA380 summing node, each 2 MOhm / 10 pF feedback network returns to `VOUT1..4`, each bounded VBIAS trim stays below the OPA380 common-mode guard, and each `VOUTx` feeds the AD7606 +/-5 V input. At VBIAS = 1.5 V and RF = 2 MOhm it reports about +1.40 uA / -0.70 uA one-sided OPA380 headroom. The SFH2201 1000 lx short-circuit-current example intentionally fails because 76 uA would require about 152 V of TIA swing at 2 MOhm. | High for first-order TIA topology/range math; optical power, ambient shielding, noise/stability, and production calibration still need measurement. Define the real Vivonics optical photocurrent range before relying on the signal-PD readout. |
| `circuits/review/signoff/2026-07-05-tia-first-article-calibration-signoff.md` | TIA readout first-article calibration signoff. | Requires current 2 Mohm feedback to be treated as a high-sensitivity, low-current bench range; starts at VBIAS target 1.5 V; requires dark-offset capture with covered/shielded SFH2201 detectors, limited ambient light, one-channel-at-a-time known electrical current injection or calibrated optical input, RF/trim state, VBIAS, dark counts, response slope, noise floor, saturation threshold, known input level, and AD7606 +/-5 V scaling confirmation. | Allows controlled first-article TIA calibration; production measurement release, ambient shielding, optical-path calibration, noise/stability proof, firmware implementation, and final RF/VBIAS settings remain open. |
| `circuits/review/signoff/2026-07-05-tia-category-review.md` | Severity-ranked signal-PD TIA calibration category review artifact. | Records that signal-PD/TIA calibration is rank 5 high, summarizes the passing topology/range/signoff/template checks and the expected-fail bright-ambient guard, and maps the `TIA_READOUT_RANGE_CALIBRATION` ledger rows to the exact evidence needed before closure. | High for order-readiness traceability; does not close measured D1-D4 calibration, ambient saturation policy, noise/stability, firmware saturation behavior, or production optical measurement release. |
| `circuits/check_passive_derating.py` | Passive voltage/power derating. | Verifies every assembled capacitor, resistor, and SMD trimmer MPN has an explicit bench rating entry and checks steady-state voltage/power utilization against the local derating policy. Current worst cases are `C68` 10 uF laser-buck output capacitance at 43.1% capacitor voltage utilization, `R63` 10 k RJ45/input resistor at 48.4% resistor power utilization, and `R63` at 29.3% resistor voltage utilization. | High for bench steady-state stress assumptions; not a pulse/surge/lifecycle/procurement AVL check. |
| `circuits/check_passive_avl_lock.py` | Passive first-article AVL lock guardrail. | Verifies `docs/part-notes/passive-first-article-avl-lock.md` matches the exported netlist for 24 passive MPN/LCSC pairs and 129 capacitor/resistor/trimmer placements. The lock captures the JLCPCB first-article C-code set and keeps quote-time lifecycle/stock, substitution review, pulse/surge/current derating, and board-temperature evidence visible as remaining production work. | High for preventing silent passive BOM drift before first-article ordering; not live JLCPCB stock/lifecycle proof or measured board-temperature evidence. |
| `circuits/check_procurement_release_template.py` | Quote-time procurement and production-derating template guardrail. | Verifies `circuits/review/calibration/quote_time_procurement_release_template.csv` includes rows for JLCPCB BOM/POS quote acceptance, locked passive AVL review, substitution review, pulse/surge/current derating, board-temperature evidence, and order archive commit linkage. | High for preventing skipped order/release evidence; not live JLCPCB stock, accepted substitutions, measured temperature data, or production release. |
| `circuits/review/signoff/2026-07-05-passive-category-review.md` | Severity-ranked passive AVL/derating category review artifact. | Records that passive procurement and derating is rank 7 medium, summarizes the passing steady-state passive derating, first-article passive AVL lock, procurement-template, and JLCPCB package checks, and maps the `PASSIVE_PRODUCTION_AVL_AND_DERATING` ledger rows to the exact evidence needed before closure. | Medium for order-readiness traceability; does not close live JLCPCB quote acceptance, substitutions, production pulse/surge/current derating, or measured board-temperature evidence. |
| `circuits/check_first_article_release_evidence.py` | First-article release evidence ledger guardrail. | Verifies `circuits/review/calibration/first_article_release_evidence.csv` contains exact closure rows for the seven deferred blocker categories, keeps each row `OPEN` until measured/procurement/firmware evidence exists, and requires a `CLOSED` row to point at an evidence file containing blocker-specific tokens. | High for preventing the blocker registry from being cleared by prose alone; current rows are intentionally open until real first-article evidence exists, and the release-readiness checker derives its open blocker list from this ledger. |
| `circuits/check_laser_controller_release_readiness.py` | Open first-article/production blocker registry. | Returns `BLOCKED` for blocker categories with open rows in `first_article_release_evidence.csv`: monitor-PD front-end range/calibration, signal-PD TIA range/calibration, per-diode laser thermal budget, AP2112 bring-up measurement or regulator change, 24 V barrel/RJ45 input protection/adapter/harness rating, buck layout/thermal signoff, passive production AVL/derating, and AD7606 firmware/timing/range signoff. It also verifies the static blocker registry and evidence-ledger blocker IDs agree. SS14 C2480 order identity/polarity, Bourns 3224W wiper orientation, selected direct-laser MPN/footprint mapping, return-path layout review, and KiCad ERC/DRC/parity package evidence are closed by 2026-07-04/2026-07-07 signoffs. | High for keeping non-automatable blockers visible; blockers still require physical review, measurement, source lock, or design change before bench-use or production release. |
| `circuits/run_laser_controller_review.py` | Review/CI wrapper. | Runs the available generated schematic, source-register, source-document, PCB, generated-copper, thermal, open first-article/production blocker, expected-fail, headless Pcbnew DRC, native courtyard-overlap triage, placement, whitespace, JLCPCB package, and KiCad CLI ERC/DRC/parity checks. Its report now separates JLCPCB order-package status from first-article/production release status; `--release` still exits nonzero while deferred first-article/production blockers remain open. | High for repeatability; not a waiver for future part substitutions, physical first-article measurement, or human visual review. |
| `circuits/review/signoff/2026-07-04-kicad-drc-zero-violations.md` | KiCad GUI DRC partial signoff artifact. | Records the captured 2026-07-04 Pcbnew DRC dialog showing refilled-zone DRC with `Violations (0)` and `Unconnected Items (0)`, with screenshot evidence in the adjacent PNG. The same artifact explicitly records `Schematic Parity (not run)`. | Useful board-rule evidence for the current PCB, but not a release waiver for native KiCad ERC, native schematic parity, or ignored-test review. |
| `circuits/review/signoff/2026-07-04-direct-laser-mpn-footprint-signoff.md` | Direct laser MPN/footprint signoff artifact. | Records the selected LD1-LD4 MPNs, colors, direct TO18/TO56 footprints, PCB pad-net mapping, LD4 case no-connect decision, and `MPD_RAW4` spare/open decision. | Closes the selected direct-laser MPN-to-footprint mapping blocker for this PCB; physical orientation inspection, current/thermal proof, MPD calibration, and laser safety behavior remain open. |
| `circuits/review/signoff/2026-07-05-laser-command-limiter-signoff.md` | Per-channel laser command limiter signoff artifact. | Records the LD1-LD4 limiter refs, values, MPNs, LCSC order identities, analog current limits, targeted verification commands, and regenerated BOM/POS package state. | Closes the electrical schematic/BOM/CPL portion of the old common-clamp risk; board temperature, optical output, firmware clamp behavior, loop dynamics, and laser safety remain bring-up blockers. |
| `circuits/review/signoff/2026-07-05-laser-first-article-bringup-signoff.md` | Laser first-article optical/thermal bring-up signoff artifact. | Records the one-channel-at-a-time laser safety, firmware clamp, `LASER_V+`, external optical-power, and driver/sense-temperature measurement requirements for first-article bring-up. | Does not close optical safety release or measured thermal/optical evidence; it prevents the passing electrical current-limit gates from being treated as a complete laser release. |
| `circuits/review/signoff/2026-07-05-monitor-pd-first-article-calibration-signoff.md` | Monitor-PD first-article calibration signoff artifact. | Records LD1-LD3 monitor-capable source calibration requirements, LD4/MPD4 spare/open treatment, external optical-meter calibration, current-clamp priority, and monitor open/short/saturation/current-without-monitor-response fail-shutoff requirements. | Does not close measured MPD calibration, production APC, normalization, optical-safety release, or firmware implementation. |
| `circuits/review/signoff/2026-07-05-tia-first-article-calibration-signoff.md` | TIA readout first-article calibration signoff artifact. | Records the VOUT1..4 dark-offset, ambient shielding, known electrical/optical input, RF/VBIAS, response slope, noise floor, saturation threshold, AD7606 +/-5 V scaling, and firmware saturation/out-of-range requirements. | Does not close measured optical readout calibration, production measurement release, noise/stability proof, or firmware implementation. |
| `circuits/review/signoff/2026-07-05-ad7606-first-article-readback-signoff.md` | AD7606 first-article firmware/readback signoff artifact. | Records the SCLK/sample-rate/read-after-conversion limits, RESET/CONVST/BUSY/CS timing requirements, two-DOUT readback, VOUT1..4 channel-order check, RANGE/OS/scaling assumptions, and known-input readback requirement. | Does not close firmware implementation, scoped timing evidence, analog accuracy, known-input data, or production measurement release. |
| `circuits/review/signoff/2026-07-05-ap632-output-capacitor-signoff.md` | AP632 output capacitor signoff artifact. | Records the C64-C65/C67-C68 move to Samsung `CL21A226MAQNNNE` 22 uF 25 V 0805 ceramics, JLCPCB/LCSC `C45783`, and the passing `datasheet-recommended-components`, AP632 PCB, passive derating, BOM, and POS checks. | Closes the local AP632 output-capacitance recommendation blocker; VIN24 input protection, buck ripple/transient/stability, switch-loop layout, and temperature measurement remain open. |
| `circuits/review/signoff/2026-07-05-ap632-first-article-buck-validation-signoff.md` | AP632 first-article buck validation signoff artifact. | Records the J5/current-limit/RJ45-disabled input boundary, BUCK_5V/+5V/LASER_V+ rail-verification requirement, 9.3 V-class LASER_V+ assumption, startup/ripple/load-step measurement, and U15/U16/L1/L2/D6/output-cap temperature measurement requirements. | Does not close production input protection, RJ45 power injection, hot-plug behavior, measured buck stability/ripple/temperature data, or production release. |
| `circuits/review/signoff/2026-07-04-return-path-layout-signoff.md` | Return-path layout signoff artifact. | Records the current board's filled In1.Cu GND plane, GND via count and sizes, local laser-sense and buck-return via distances, custom PCB spacing evidence, layout-geometry pass, and generated-copper release-gate pass. | Closes the return-path layout review blocker for this PCB artifact; KiCad ERC/parity, native KiCad DRC, measurements, and reroute-triggered re-review remain separate. |
| `circuits/review/signoff/2026-07-05-assembly-courtyard-waiver-signoff.md` | Assembly courtyard waiver signoff artifact. | Records the current native Pcbnew DRC/courtyard triage state: 4 courtyard-only warnings, 0 F.Fab/body-box overlaps, all 4 warning pairs explicitly waived, and the JLCPCB package gate passing. | Accepts the current courtyard-only warnings for controlled first-article ordering; JLCPCB assembly viewer, physical fit inspection, KiCad ERC/parity, and re-triage after placement/package changes remain required. |
| `circuits/review/signoff/2026-07-05-release-category-matrix.md` | Ranked release-category matrix artifact. | Records the closed CAD/order-package gate, ranks the seven remaining deferred first-article and production-release categories by spend/safety impact, and maps each category to the active release-readiness blocker: 24 V input/buck validation, laser safety/thermal, +3V3 regulator limits, AD7606 readback, signal-PD calibration, monitor-PD calibration, and quote-time procurement/derating. | Keeps the order decision grounded in first-article boundaries; it does not close any external measurement, JLCPCB viewer, procurement, firmware, or production-release blocker. |
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

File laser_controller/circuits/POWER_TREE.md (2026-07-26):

# Bench Laser Controller Power Tree

Generated design state: 2026-06-30.

This is the rail and power-path review for `laser_controller.kicad_sch` and
`laser_controller.kicad_pcb`. It complements the netlist/PCB checkers; it does
not replace GUI ERC, schematic parity, native KiCad PCB DRC, or bench
measurements.

## First-Article Finding — 2026-07-26

The 24 V input is intended to be the only external power source needed for the
board: U15 generates `/POWER_IO/BUCK_5V`, D6 feeds the board `+5V` rail, U11
then generates `+3V3`, and U16 independently generates `LASER_V+`. USB VBUS is
only an alternate diode-OR source through D5; it is not a required second rail.

The assembled first article measured only `4.3 V` and later `4.6 V` at U14
AD7606 pin 1 before an external post-OR `+5V` injection raised that point to
`5.2 V`. The AD7606 AVCC operating range is `4.75 V` to `5.25 V`. A fixed
`5.0 V` U15 output followed by D6's forward drop therefore has insufficient
guaranteed margin and explains the under-voltage observation. The same topology
exists on the USB path through D5, so connecting USB must not be treated as the
corrective action for AD7606 AVCC.

This is an open first-article power-design defect, not a missing-user-supply
requirement. Before relying on the ADC, measure D6 anode (`BUCK_5V`) and cathode
(`+5V`) simultaneously under load. Rework the source/OR topology so the
post-OR rail remains inside every downstream load's limits and the AD7606 sees
at least `4.75 V`; candidate fixes require an electrical review and include a
higher regulated pre-OR voltage, an ideal-diode path, or an approved bypass of
the unnecessary drop. Do not connect an uncontrolled second 5 V source or
assume two diode-OR inputs will raise the rail.
The PCB's copper planes follow the `~/projects/access-controller` reference
pattern: a single full-board `GND` flood on `In1.Cu` (no outer-layer `GND`
fill -- `F.Cu`/`B.Cu` are pure signal layers), and `In2.Cu` split into
exactly two simple, non-overlapping regions, `+3V3` over the MCU cluster
and `+5V` over the TIA/laser-driver clusters, satisfying
`check_laser_controller_pcb.REQUIRED_PLANE_ZONES`. `LASER_V+` and
`VIN_24V` have no dedicated zone; delivery to their loads (and delivery
from the `+3V3`/`+5V` zone edges to any load outside their region, e.g.
the `POWER_IO` buck/ADC/monitor cluster sitting in the gap between the two
regions) is meant to be explicit trunk-trace routing, not a wide flood -- see
`PCB_LAYOUT.md` for why. The current PCB artifact has filled zone definitions,
1611 routed copper segments, 236 vias, and passes the custom PCB and
generated-copper release gates. `check_schematic_pcb_parity.py` passes the
headless exported-netlist-to-current-PCB pad-net comparison. A 2026-07-04 GUI
DRC screenshot captures refilled-zone DRC with zero violations and zero
unconnected items, but native schematic parity was not run in that dialog. The
2026-07-04 return-path layout signoff captures the current
GND/via/sensitive-route review for this routed PCB.
KiCad GUI ERC and native schematic-parity evidence remain separate release
requirements.
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

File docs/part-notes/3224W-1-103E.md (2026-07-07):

# Bourns 3224W Trimmer Part Note

Source:
- Bourns 3224 datasheet: `https://www.bourns.com/pdfs/3224.pdf`
- LCSC `C81348` order source for `3224W-1-103E` 10 k trimmer.
- LCSC `C116323` order source for `3224W-1-205E` 2 M trimmer.
- 2026-07-04 PCB orientation signoff:
  `circuits/review/signoff/2026-07-04-ss14-bourns-order-source-signoff.md`.
- 2026-07-07 OPA380/Bourns orientation repair signoff:
  `circuits/review/signoff/2026-07-07-opa380-bourns-orientation-repair-signoff.md`.
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

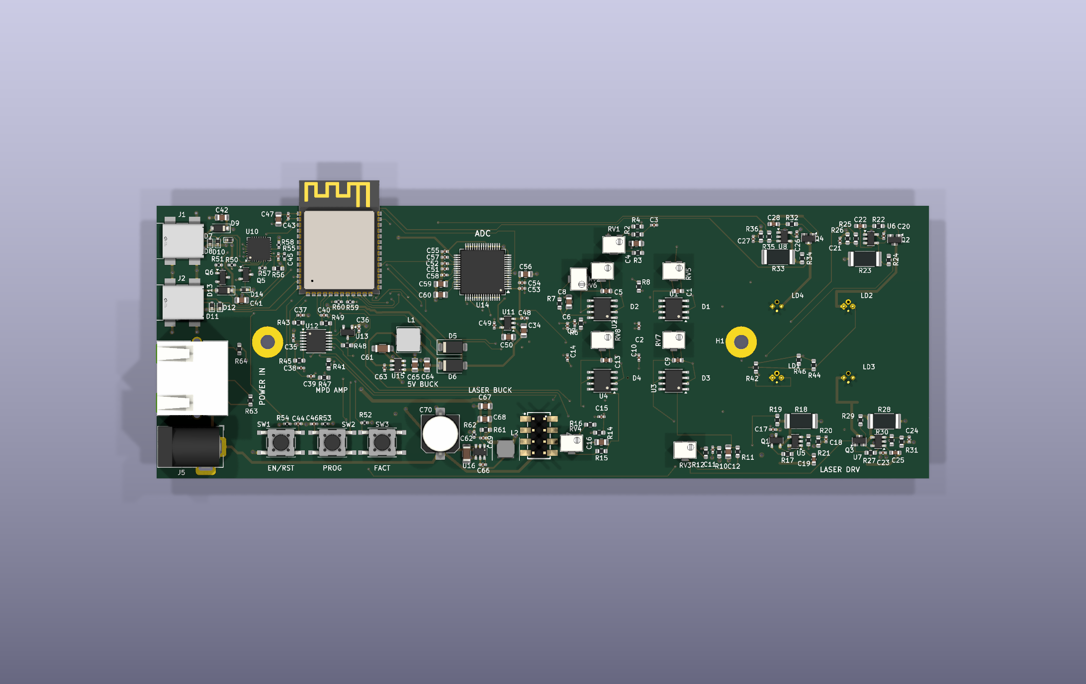
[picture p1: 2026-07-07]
laser_controller/circuits/review/generated/laser_controller_top_render.png

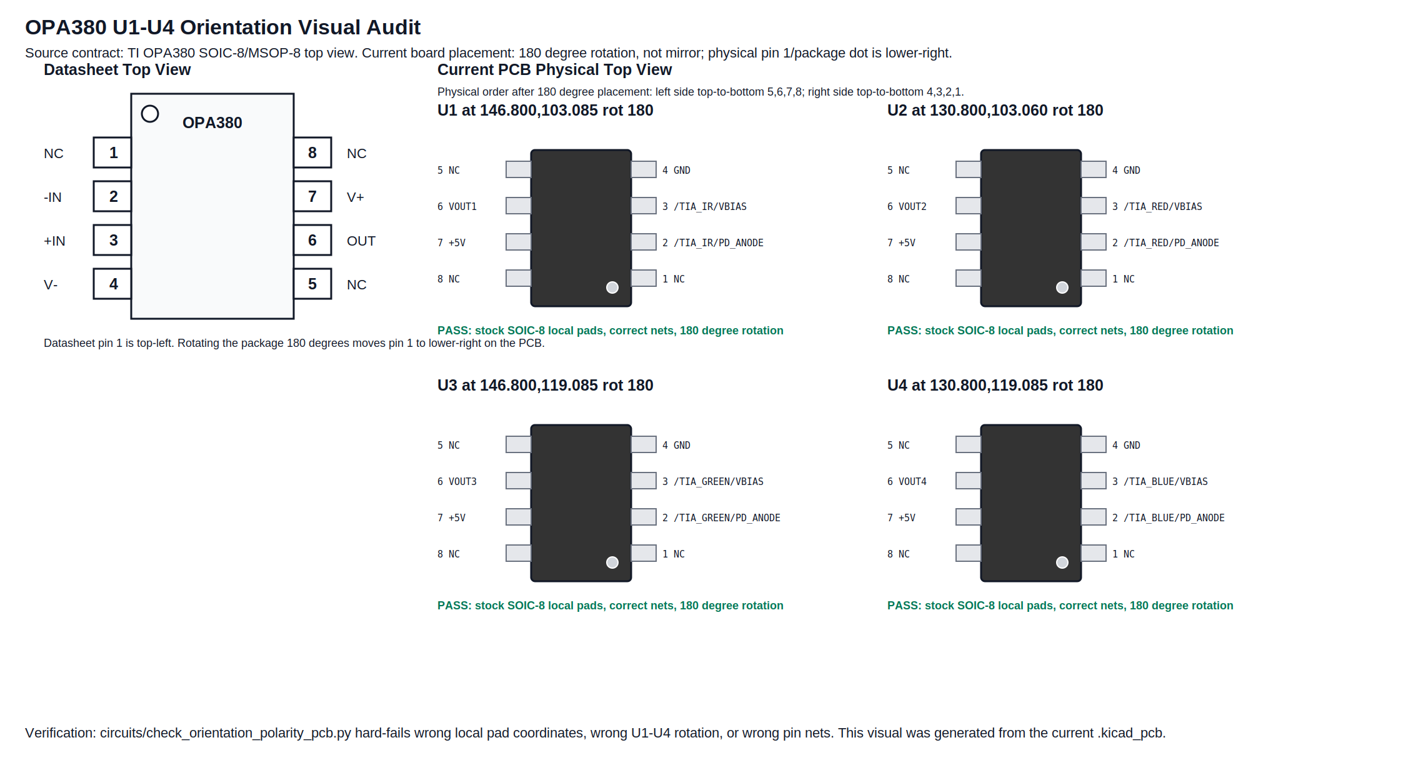
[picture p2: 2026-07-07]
laser_controller/circuits/review/generated/opa380_orientation_visual_audit.png

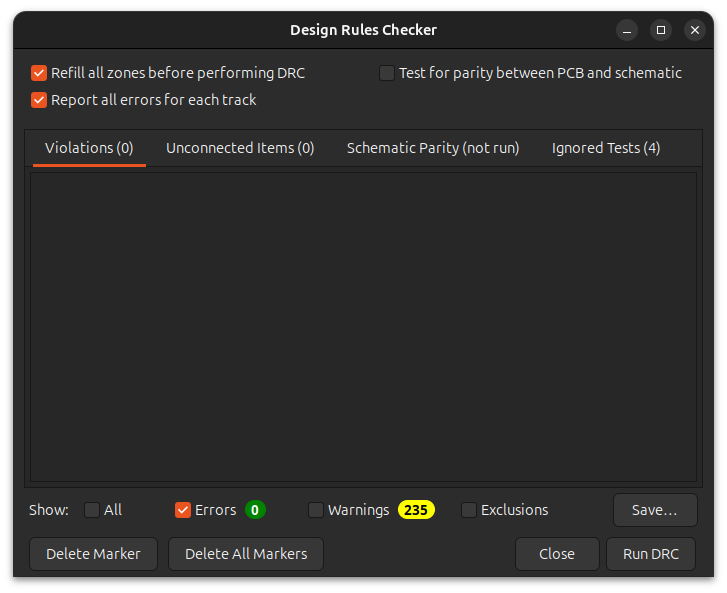
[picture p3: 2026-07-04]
laser_controller/circuits/review/signoff/2026-07-04-kicad-drc-zero-violations.png

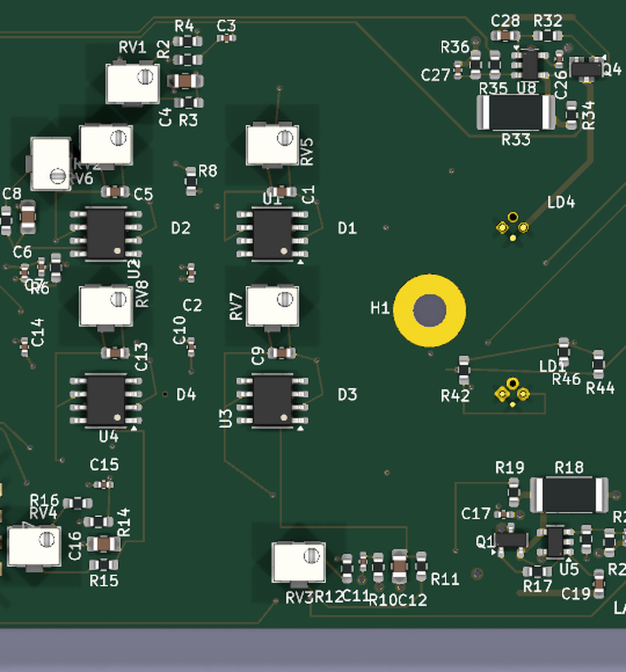
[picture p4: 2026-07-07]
laser_controller/circuits/review/generated/laser_controller_tia_top_render_crop.png

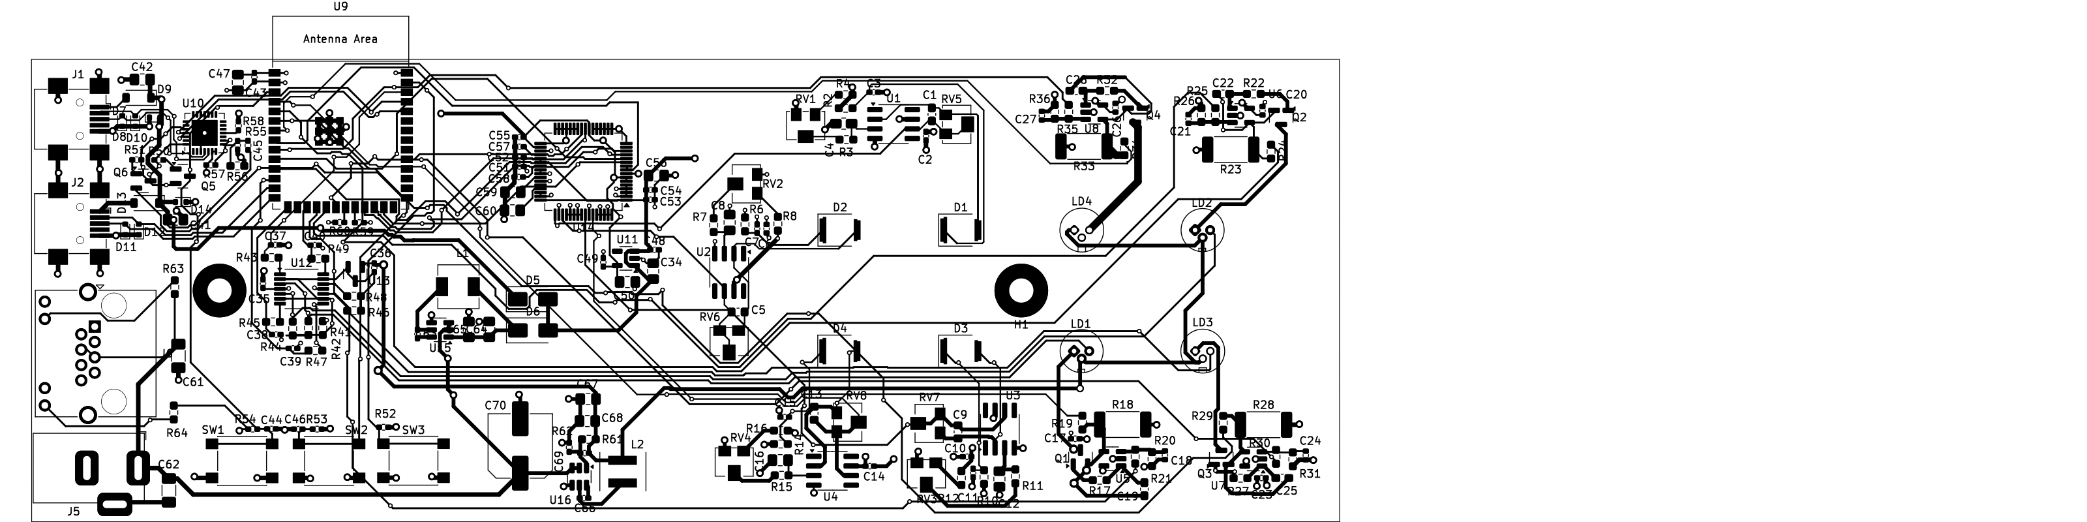
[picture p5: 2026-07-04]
laser_controller/circuits/laser_controller_board.png

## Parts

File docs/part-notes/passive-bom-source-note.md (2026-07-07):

# Passive BOM Source Note

Source:
- Generated BOM: `circuits/laser_controller_bom_jlcpcb.csv`
- Generated netlist fields: value, footprint, `Part Number`, and `LCSC`
- Checker: `circuits/check_laser_controller_netlist.py`
- Derating checker: `circuits/check_passive_derating.py`
- First-article passive AVL lock: `docs/part-notes/passive-first-article-avl-lock.md`

Current passive families:
- 10 pF C0G 0603: `CC0603JRNPO9BN100`, LCSC `C106245`
- 100 nF 0402: `0402B104K160CT`, LCSC `C83056`
- 1 uF 0402: `HGC0402R5105K250NTEJ`, LCSC `C7472946`
- 10 uF 1206 50 V: `CL31B106KBHNNNE`, LCSC `C89632`
- 22 uF 100 V SMD electrolytic: `RVT2A220M0810 22UF 100V`, LCSC/JLCPCB `C970665`
- 10 uF 0805: `CL21A106KAYNNNG`, LCSC `C318691`
- 1 k / 10 k / 30 k / 22 ohm / 10 M 0603 resistor families as encoded in
  the generated BOM and netlist checker.
- 240 ohm 0603 monitor-PD sense resistor: `RTT032400FTP`, LCSC/JLCPCB `C103446`.
- 2.49 k 0603 monitor-bias sink resistor: `0603WAF2491T5E`, LCSC/JLCPCB `C22908`.
- 237 k 0603 AP63200 feedback resistor: `FRC0603F2373TS`, LCSC `C2998117`.
- 10 ohm 2512 2 W laser sense resistors: `HoCR2512-2W-10R-1%`, LCSC `C5123624`.
- Bourns 3224W SMD trimmers: `3224W-1-103E` / LCSC `C81348` for VBIAS,
  and `3224W-1-205E` / LCSC `C116323` for TIA feedback trim.

Current verification:
- The netlist checker asserts value, footprint, MPN, and LCSC for every passive
  instance.
- The passive derating checker asserts that every assembled capacitor, resistor,
  and SMD trimmer MPN has an explicit bench rating entry and stays below the
  local steady-state voltage/power policy. Current worst cases are the
  `C68` 10 uF laser-buck output capacitor at 43.1% voltage utilization,
  `R63` 10 k RJ45/input resistor at 48.4% power utilization, and `R63` at
  29.3% voltage utilization.
- The PCB checker verifies pad-net assignment, proximity, copper clearance, and
  route class membership.

Open production gap:
- Commodity passive voltage ratings and resistor steady-state power are now
  encoded for the bench design, and the first-article passive MPN/LCSC set is
  locked against the exported netlist. Production still needs quote-time
  lifecycle/stock review, approved substitute policy, pulse/surge/current derating,
  final manufacturer datasheets for every orderable passive, and
  board-temperature measurement.

First-article upload note:
- The JLCPCB upload manifest is
  `circuits/fab/laser_controller_jlcpcb_upload_manifest.md`. For the current
  five-board first-article order, `R41` was moved from thin-stock `C103460` to
  `C22908`. `C70` was moved from short `C242011` to same-footprint JLCPCB SMT
  part `C970665`. If JLCPCB flags it again, use a same-footprint quote-page
  substitute with a new checkpoint commit, or hand-place the affected part.

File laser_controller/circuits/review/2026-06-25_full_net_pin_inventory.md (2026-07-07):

# Laser Controller Full Net/Pin Inventory

Generated from KiCad exported netlist and the current generated PCB artifact.

Schematic references are generated globally unique before KiCad netlist export. Logical route names such as `LASER_GREEN/R12` are resolved through `circuit_designators.py`; physical net nodes use unique refs such as `R29` and `Q3`.

## PCB Trace State

| Metric | Value |
|---|---:|
| `footprint_objects` | 181 |
| `referenced_footprints` | 0 |
| `unique_references` | 0 |
| `copper_layers` | 4 |
| `segments` | 0 |
| `vias` | 0 |
| `zones` | 0 |
| `pad_net_lines` | 0 |
| `net_table_entries` | 0 |
| `keepout_zones` | 0 |
| `gnd_reference_zone_defs` | 0 |
| `placement_proximity_checks` | 39/111 PASS |
| `intentional_unnetted_pad_instances` | 79 |
| `connected_critical_local_route_links` | 111/111 |
| `multi_pad_nets` | 110 |
| `explicitly_routed_multi_pad_nets` | 107 |
| `unrouted_multi_pad_nets` | 1 |
| `zone_or_rail_pending_multi_pad_nets` | 2 |

### Routed Copper Geometry By Net Class

This table reports the generated routed copper that exists in the current PCB artifact. It does not waive KiCad zone refill, DRC, or manual current-path review.

| Net Class | Segment Widths | Via Size/Drill |
|---|---|---|
| `Laser_Current` | 0.20mm x28, 0.60mm x47, 0.80mm x45 | 1.20/0.60mm x5 |
| `Power_Rails` | 0.15mm x1, 0.20mm x34, 0.22mm x4, 0.25mm x195, 0.30mm x6, 0.50mm x131, 0.60mm x138 | 0.60/0.30mm x65, 1.00/0.50mm x79, 1.00/0.60mm x1 |
| `Switching_Power` | 0.40mm x14 | - |
| `Switcher_Control` | 0.20mm x11 | - |
| `USB` | 0.25mm x49 | 0.60/0.30mm x2 |
| `TIA_Sensitive` | 0.18mm x29, 0.20mm x108 | 0.60/0.30mm x26 |
| `Monitor_ADC` | 0.20mm x302 | 0.60/0.30mm x37 |
| `Laser_Control` | 0.20mm x147 | 0.60/0.30mm x22 |
| `Digital_Control` | 0.20mm x255, 0.25mm x4 | 0.60/0.30mm x35 |

### USB Route Detail

USB is checked as the copied MCU-sheet connector-to-endpoint routed copper chain for each D+/D- leg. The PCB checker fails if either chain exceeds the generated-board length limit, uses vias, leaves F.Cu, changes width, or exceeds the pair-skew limit.

Pair routed-copper skew: 0.00 mm. PASS: USB generated-board route quality gate passed

| Chain | Section | Net | Segments | Length | Geometry | Status |
|---|---|---|---:|---:|---|---|
| `USB-UART D-` | J1 D- to CP2102N D- | `/MCU_ESP32-S3/D-` | 14 | 21.92 mm | B.Cu, F.Cu; widths 0.25 mm; vias 2 | PASS: measured route section is present |
| `USB-UART D-` | total | `-` | 14 | 21.92 mm | B.Cu, F.Cu; widths 0.25 mm; vias 2 | PASS: measured chain is inside generated-board USB limits |
| `USB-UART D+` | J1 D+ to CP2102N D+ | `/MCU_ESP32-S3/D+` | 16 | 20.28 mm | F.Cu; widths 0.25 mm; vias 0 | PASS: measured route section is present |
| `USB-UART D+` | total | `-` | 16 | 20.28 mm | F.Cu; widths 0.25 mm; vias 0 | PASS: measured chain is inside generated-board USB limits |
| `Native USB D-` | J2 D- to ESP32 GPIO19 | `/MCU_ESP32-S3/IO19` | 9 | 26.66 mm | F.Cu; widths 0.25 mm; vias 0 | PASS: measured route section is present |
| `Native USB D-` | total | `-` | 9 | 26.66 mm | F.Cu; widths 0.25 mm; vias 0 | PASS: measured chain is inside generated-board USB limits |
| `Native USB D+` | J2 D+ to ESP32 GPIO20 | `/MCU_ESP32-S3/IO20` | 10 | 26.22 mm | F.Cu; widths 0.25 mm; vias 0 | PASS: measured route section is present |
| `Native USB D+` | total | `-` | 10 | 26.22 mm | F.Cu; widths 0.25 mm; vias 0 | PASS: measured chain is inside generated-board USB limits |

### Laser Current Trace Detail

This table separates the high-current laser cathode/load paths from source-sense feedback copper. Any `BLOCKER` row is routed connectivity evidence only; it is not accepted current-path layout.

| Net | Layer | Width | Segments | Total Length | Role | Status |
|---|---|---:|---:|---:|---|---|
| `/LASER_BLUE/FB` | `F.Cu` | 0.20 mm | 9 | 13.96 mm | source-sense feedback node | REVIEW: contains AO3400A source/sense current path plus low-current feedback/telemetry stubs |
| `/LASER_BLUE/FB` | `F.Cu` | 0.60 mm | 6 | 14.62 mm | source-sense feedback node | REVIEW: contains AO3400A source/sense current path plus low-current feedback/telemetry stubs |
| `/LASER_GREEN/FB` | `F.Cu` | 0.20 mm | 3 | 5.55 mm | source-sense feedback node | REVIEW: contains AO3400A source/sense current path plus low-current feedback/telemetry stubs |
| `/LASER_GREEN/FB` | `F.Cu` | 0.60 mm | 9 | 17.97 mm | source-sense feedback node | REVIEW: contains AO3400A source/sense current path plus low-current feedback/telemetry stubs |
| `/LASER_IR/FB` | `F.Cu` | 0.20 mm | 3 | 6.21 mm | source-sense feedback node | REVIEW: contains AO3400A source/sense current path plus low-current feedback/telemetry stubs |
| `/LASER_IR/FB` | `F.Cu` | 0.60 mm | 9 | 17.70 mm | source-sense feedback node | REVIEW: contains AO3400A source/sense current path plus low-current feedback/telemetry stubs |
| `/LASER_RED/FB` | `F.Cu` | 0.20 mm | 13 | 19.69 mm | source-sense feedback node | REVIEW: contains AO3400A source/sense current path plus low-current feedback/telemetry stubs |
| `LASER_N1` | `B.Cu` | 0.60 mm | 3 | 14.64 mm | laser cathode load path | PASS: generated cathode route meets current width/length limits |
| `LASER_N1` | `F.Cu` | 0.60 mm | 2 | 0.95 mm | laser cathode load path | PASS: generated cathode route meets current width/length limits |
| `LASER_N2` | `F.Cu` | 0.60 mm | 7 | 26.54 mm | laser cathode load path | PASS: generated cathode route meets current width/length limits |
| `LASER_N3` | `F.Cu` | 0.60 mm | 7 | 21.30 mm | laser cathode load path | PASS: generated cathode route meets current width/length limits |
| `LASER_N4` | `F.Cu` | 0.60 mm | 4 | 17.56 mm | laser cathode load path | PASS: generated cathode route meets current width/length limits |
| `LASER_VP` | `B.Cu` | 0.80 mm | 9 | 73.65 mm | laser current net | REVIEW |
| `LASER_VP` | `F.Cu` | 0.80 mm | 21 | 50.53 mm | laser current net | REVIEW |
| `LASER_VP` | `In2.Cu` | 0.80 mm | 15 | 88.73 mm | laser current net | REVIEW |

### Laser Sense Return Detail

Each 10 ohm 2512 source-sense resistor must return into the GND reference plane through a distinct high-current 0.60/0.30 mm via within 6.0 mm of routed GND copper.

| Channel | Sense GND Pad | Routed GND Path | Via | Via Size/Drill | Status |
|---|---|---:|---|---|---|
| `LASER_IR` | `R18.2` | 1.45 mm | `(179.80, 128.18)` | 1.00/0.50 mm | PASS: routed sense return reaches an assigned high-current GND via |
| `LASER_RED` | `R23.2` | 1.53 mm | `(185.05, 91.88)` | 1.00/0.50 mm | PASS: routed sense return reaches an assigned high-current GND via |
| `LASER_GREEN` | `R28.2` | 1.72 mm | `(198.68, 128.10)` | 1.00/0.50 mm | PASS: routed sense return reaches an assigned high-current GND via |
| `LASER_BLUE` | `R33.2` | 1.51 mm | `(168.62, 91.45)` | 1.00/0.50 mm | PASS: routed sense return reaches an assigned high-current GND via |

PCB pad-net assignment, stackup, net classes, and footprint-internal keepouts are present and auditable, but trace-level electrical review is still blocked until placement, routing, board-level zones, and KiCad DRC exist. Current board evidence has no routed segments, no vias, and no board-level zones.

### Reviewed Rail/Zone Pending Nets

These are the only multi-pad nets currently allowed to remain route/zone pending in the current PCB. The PCB checker fails if a different rail or any signal/control net enters this state.

| Net | Pads | Copper Components | Review Status | Required Release Action | Component Groups |
|---|---:|---:|---|---|---|
| `GND` | 166 | 2 | REVIEWED_PENDING | Maintain the signed-off In1.Cu GND reference zone and keep laser-current return paths out of TIA summing-node returns after any reroute. | H1.1, H2.1, D14.1, C67.2, C44.2, C26.2, C55.2, C56.2 ... \| C12.2 |
| `VIN_24V` | 13 | 2 | REVIEWED_PENDING | Route the J5 barrel/J6 RJ45 input to the AP63205/AP63200 input capacitors and VIN pins with protected, short 24 V copper. | J7.7, J7.8 \| C62.1, C61.1, U16.2, U16.3, U15.2, U15.3, J5.1, C70.1 ... |

### Placement Proximity Checks

These generated-board checks keep USB protection, ESP32-S3 support parts, AP2112 decoupling, every TIA input/feedback/decoupling/bias cluster, every laser gate/sense/control/compensation cluster, and every monitor-PD sense/reference/ADC-isolation cluster close to the pins they serve.
Rows marked `REVIEW` exceed generated ideal-placement targets; release gating is handled by the focused geometry, package, DRC, and connectivity checks.

| Check | Actual | Limit | Status |
|---|---:|---:|---|
| USB UART D- connector to ESD | 5.21 mm | 7.50 mm | PASS |
| USB UART D+ connector to ESD | 3.50 mm | 9.50 mm | PASS |
| USB UART D- ESD to CP2102N | 10.77 mm | 10.00 mm | REVIEW |
| USB UART D+ ESD to CP2102N | 11.88 mm | 10.00 mm | REVIEW |
| Native USB D- connector to ESD | 5.74 mm | 7.50 mm | PASS |
| Native USB D+ connector to ESD | 3.88 mm | 9.50 mm | PASS |
| Native USB D- ESD to ESP32 GPIO19 | 18.57 mm | 4.50 mm | REVIEW |
| Native USB D+ ESD to ESP32 GPIO20 | 20.06 mm | 4.50 mm | REVIEW |
| AP2112 input cap at VIN | 2.95 mm | 4.00 mm | PASS |
| AP2112 100n output cap at VOUT | 1.86 mm | 4.00 mm | PASS |
| AP2112 bulk output cap at VOUT | 2.19 mm | 4.00 mm | PASS |
| ESP32 local 3V3 decap | 2.67 mm | 3.00 mm | PASS |
| ESP32 EN capacitor | 44.54 mm | 4.00 mm | REVIEW |
| ESP32 EN pull-up | 44.61 mm | 5.00 mm | REVIEW |
| ESP32 BOOT pull-up | 33.03 mm | 4.00 mm | REVIEW |
| TIA_IR photodiode anode to OPA380 -IN | 2.68 mm | 5.50 mm | PASS |
| TIA_IR feedback trimmer at OPA380 -IN | 10.74 mm | 3.50 mm | REVIEW |
| TIA_IR feedback capacitor at OPA380 -IN | 4.77 mm | 2.50 mm | REVIEW |
| TIA_IR feedback trimmer at OPA380 OUT | 6.96 mm | 4.50 mm | REVIEW |
| TIA_IR feedback capacitor at OPA380 OUT | 4.27 mm | 2.50 mm | REVIEW |
| TIA_IR OPA380 supply decoupling | 6.45 mm | 2.50 mm | REVIEW |
| TIA_IR PD bias resistor at cathode | 23.13 mm | 4.50 mm | REVIEW |
| TIA_IR PD cathode bypass at cathode | 23.20 mm | 3.00 mm | REVIEW |
| TIA_IR VBIAS resistor at OPA380 +IN | 15.35 mm | 5.00 mm | REVIEW |
| TIA_IR VBIAS capacitor at OPA380 +IN | 17.18 mm | 4.00 mm | REVIEW |
| TIA_RED photodiode anode to OPA380 -IN | 2.68 mm | 5.50 mm | PASS |
| TIA_RED feedback trimmer at OPA380 -IN | 10.72 mm | 3.50 mm | REVIEW |
| TIA_RED feedback capacitor at OPA380 -IN | 4.75 mm | 2.50 mm | REVIEW |
| TIA_RED feedback trimmer at OPA380 OUT | 6.93 mm | 4.50 mm | REVIEW |
| TIA_RED feedback capacitor at OPA380 OUT | 4.25 mm | 2.50 mm | REVIEW |
| TIA_RED OPA380 supply decoupling | 6.47 mm | 2.50 mm | REVIEW |
| TIA_RED PD bias resistor at cathode | 14.47 mm | 4.50 mm | REVIEW |
| TIA_RED PD cathode bypass at cathode | 16.16 mm | 3.00 mm | REVIEW |
| TIA_RED VBIAS resistor at OPA380 +IN | 12.07 mm | 5.00 mm | REVIEW |
| TIA_RED VBIAS capacitor at OPA380 +IN | 9.96 mm | 4.00 mm | REVIEW |
| TIA_GREEN photodiode anode to OPA380 -IN | 2.68 mm | 5.50 mm | PASS |
| TIA_GREEN feedback trimmer at OPA380 -IN | 11.24 mm | 3.50 mm | REVIEW |
| TIA_GREEN feedback capacitor at OPA380 -IN | 5.27 mm | 2.50 mm | REVIEW |
| TIA_GREEN feedback trimmer at OPA380 OUT | 7.42 mm | 4.50 mm | REVIEW |
| TIA_GREEN feedback capacitor at OPA380 OUT | 4.68 mm | 2.50 mm | REVIEW |
| TIA_GREEN OPA380 supply decoupling | 7.48 mm | 2.50 mm | REVIEW |
| TIA_GREEN PD bias resistor at cathode | 15.75 mm | 4.50 mm | REVIEW |
| TIA_GREEN PD cathode bypass at cathode | 15.55 mm | 3.00 mm | REVIEW |
| TIA_GREEN VBIAS resistor at OPA380 +IN | 19.60 mm | 5.00 mm | REVIEW |
| TIA_GREEN VBIAS capacitor at OPA380 +IN | 18.31 mm | 4.00 mm | REVIEW |
| TIA_BLUE photodiode anode to OPA380 -IN | 2.68 mm | 5.50 mm | PASS |
| TIA_BLUE feedback trimmer at OPA380 -IN | 11.24 mm | 3.50 mm | REVIEW |
| TIA_BLUE feedback capacitor at OPA380 -IN | 5.27 mm | 2.50 mm | REVIEW |
| TIA_BLUE feedback trimmer at OPA380 OUT | 7.42 mm | 4.50 mm | REVIEW |
| TIA_BLUE feedback capacitor at OPA380 OUT | 4.68 mm | 2.50 mm | REVIEW |
| TIA_BLUE OPA380 supply decoupling | 7.48 mm | 2.50 mm | REVIEW |
| TIA_BLUE PD bias resistor at cathode | 15.31 mm | 4.50 mm | REVIEW |
| TIA_BLUE PD cathode bypass at cathode | 12.52 mm | 3.00 mm | REVIEW |
| TIA_BLUE VBIAS resistor at OPA380 +IN | 16.50 mm | 5.00 mm | REVIEW |
| TIA_BLUE VBIAS capacitor at OPA380 +IN | 14.50 mm | 4.00 mm | REVIEW |
| LASER_IR TLV9001 OUT to gate resistor | 2.70 mm | 3.50 mm | PASS |
| LASER_IR gate resistor to AO3400A gate | 3.33 mm | 2.50 mm | REVIEW |
| LASER_IR AO3400A source to sense resistor | 5.49 mm | 2.20 mm | REVIEW |
| LASER_IR sense feedback to TLV9001 -IN | 3.62 mm | 6.00 mm | PASS |
| LASER_IR isolated ISENSE tap at sense resistor | 2.38 mm | 3.50 mm | PASS |
| LASER_IR TLV9001 supply decoupling | 4.83 mm | 2.50 mm | REVIEW |
| LASER_IR PWM input resistor at TLV9001 +IN | 1.88 mm | 2.50 mm | PASS |
| LASER_IR command limiter at TLV9001 +IN | 4.09 mm | 3.00 mm | REVIEW |
| LASER_IR command filter cap at TLV9001 +IN | 5.80 mm | 3.00 mm | REVIEW |
| LASER_IR compensation cap at TLV9001 -IN | 7.91 mm | 2.50 mm | REVIEW |
| LASER_IR compensation cap at TLV9001 OUT | 3.78 mm | 3.00 mm | REVIEW |
| LASER_RED TLV9001 OUT to gate resistor | 2.70 mm | 3.50 mm | PASS |
| LASER_RED gate resistor to AO3400A gate | 4.26 mm | 2.50 mm | REVIEW |
| LASER_RED AO3400A source to sense resistor | 5.85 mm | 2.20 mm | REVIEW |
| LASER_RED sense feedback to TLV9001 -IN | 3.62 mm | 6.00 mm | PASS |
| LASER_RED isolated ISENSE tap at sense resistor | 2.57 mm | 3.50 mm | PASS |
| LASER_RED TLV9001 supply decoupling | 1.94 mm | 2.50 mm | PASS |
| LASER_RED PWM input resistor at TLV9001 +IN | 2.24 mm | 2.50 mm | PASS |
| LASER_RED command limiter at TLV9001 +IN | 4.09 mm | 3.00 mm | REVIEW |
| LASER_RED command filter cap at TLV9001 +IN | 5.80 mm | 3.00 mm | REVIEW |
| LASER_RED compensation cap at TLV9001 -IN | 5.78 mm | 2.50 mm | REVIEW |
| LASER_RED compensation cap at TLV9001 OUT | 1.92 mm | 3.00 mm | PASS |
| LASER_GREEN TLV9001 OUT to gate resistor | 2.50 mm | 3.50 mm | PASS |
| LASER_GREEN gate resistor to AO3400A gate | 3.15 mm | 2.50 mm | REVIEW |
| LASER_GREEN AO3400A source to sense resistor | 5.49 mm | 2.20 mm | REVIEW |
| LASER_GREEN sense feedback to TLV9001 -IN | 3.62 mm | 6.00 mm | PASS |
| LASER_GREEN isolated ISENSE tap at sense resistor | 2.57 mm | 3.50 mm | PASS |
| LASER_GREEN TLV9001 supply decoupling | 2.26 mm | 2.50 mm | PASS |
| LASER_GREEN PWM input resistor at TLV9001 +IN | 1.88 mm | 2.50 mm | PASS |
| LASER_GREEN command limiter at TLV9001 +IN | 4.09 mm | 3.00 mm | REVIEW |
| LASER_GREEN command filter cap at TLV9001 +IN | 5.80 mm | 3.00 mm | REVIEW |
| LASER_GREEN compensation cap at TLV9001 -IN | 6.79 mm | 2.50 mm | REVIEW |
| LASER_GREEN compensation cap at TLV9001 OUT | 2.42 mm | 3.00 mm | PASS |
| LASER_BLUE TLV9001 OUT to gate resistor | 2.70 mm | 3.50 mm | PASS |
| LASER_BLUE gate resistor to AO3400A gate | 4.41 mm | 2.50 mm | REVIEW |
| LASER_BLUE AO3400A source to sense resistor | 5.77 mm | 2.20 mm | REVIEW |
| LASER_BLUE sense feedback to TLV9001 -IN | 3.62 mm | 6.00 mm | PASS |
| LASER_BLUE isolated ISENSE tap at sense resistor | 2.57 mm | 3.50 mm | PASS |
| LASER_BLUE TLV9001 supply decoupling | 1.91 mm | 2.50 mm | PASS |
| LASER_BLUE PWM input resistor at TLV9001 +IN | 2.24 mm | 2.50 mm | PASS |
| LASER_BLUE command limiter at TLV9001 +IN | 4.09 mm | 3.00 mm | REVIEW |
| LASER_BLUE command filter cap at TLV9001 +IN | 5.80 mm | 3.00 mm | REVIEW |
| LASER_BLUE compensation cap at TLV9001 -IN | 5.78 mm | 2.50 mm | REVIEW |
| LASER_BLUE compensation cap at TLV9001 OUT | 1.92 mm | 3.00 mm | PASS |
| MPD_RAW1 direct LD monitor to sense resistor | 5.86 mm | 4.00 mm | REVIEW |
| MPD_RAW1 sense resistor to INA input | 101.63 mm | 4.00 mm | REVIEW |
| MPD1 ADC resistor to filter capacitor | 1.87 mm | 2.50 mm | PASS |
| MPD_RAW2 direct LD monitor to sense resistor | 16.57 mm | 4.00 mm | REVIEW |
| MPD_RAW2 sense resistor to INA input | 114.43 mm | 4.00 mm | REVIEW |
| MPD2 ADC resistor to filter capacitor | 1.84 mm | 2.50 mm | PASS |
| MPD_RAW3 direct LD monitor to sense resistor | 12.52 mm | 4.00 mm | REVIEW |
| MPD_RAW3 sense resistor to INA input | 105.31 mm | 4.00 mm | REVIEW |
| MPD3 ADC resistor to filter capacitor | 2.63 mm | 2.50 mm | REVIEW |
| MPD_RAW4 spare sense resistor to INA input | 3.55 mm | 4.00 mm | PASS |
| MPD_AMP4 INA output to ADC resistor | 2.06 mm | 4.00 mm | PASS |
| MPD4 ADC resistor to filter capacitor | 1.81 mm | 2.50 mm | PASS |

### Critical Local Route Connectivity

These route-link checks use routed segments, vias, pad copper, and filled zones for the same local clusters. Any `UNROUTED` entries are the next routing targets; they are not waived.

| Route Link | Status |
|---|---|
| USB UART D- connector to ESD | ROUTED |
| USB UART D+ connector to ESD | ROUTED |
| USB UART D- ESD to CP2102N | ROUTED |
| USB UART D+ ESD to CP2102N | ROUTED |
| Native USB D- connector to ESD | ROUTED |
| Native USB D+ connector to ESD | ROUTED |
| Native USB D- ESD to ESP32 GPIO19 | ROUTED |
| Native USB D+ ESD to ESP32 GPIO20 | ROUTED |
| AP2112 input cap at VIN | ROUTED |
| AP2112 100n output cap at VOUT | ROUTED |
| AP2112 bulk output cap at VOUT | ROUTED |
| ESP32 local 3V3 decap | ROUTED |
| ESP32 EN capacitor | ROUTED |
| ESP32 EN pull-up | ROUTED |
| ESP32 BOOT pull-up | ROUTED |
| TIA_IR photodiode anode to OPA380 -IN | ROUTED |
| TIA_IR feedback trimmer at OPA380 -IN | ROUTED |
| TIA_IR feedback capacitor at OPA380 -IN | ROUTED |
| TIA_IR feedback trimmer at OPA380 OUT | ROUTED |
| TIA_IR feedback capacitor at OPA380 OUT | ROUTED |
| TIA_IR OPA380 supply decoupling | ROUTED |
| TIA_IR PD bias resistor at cathode | ROUTED |
| TIA_IR PD cathode bypass at cathode | ROUTED |
| TIA_IR VBIAS resistor at OPA380 +IN | ROUTED |
| TIA_IR VBIAS capacitor at OPA380 +IN | ROUTED |
| TIA_RED photodiode anode to OPA380 -IN | ROUTED |
| TIA_RED feedback trimmer at OPA380 -IN | ROUTED |
| TIA_RED feedback capacitor at OPA380 -IN | ROUTED |
| TIA_RED feedback trimmer at OPA380 OUT | ROUTED |
| TIA_RED feedback capacitor at OPA380 OUT | ROUTED |
| TIA_RED OPA380 supply decoupling | ROUTED |
| TIA_RED PD bias resistor at cathode | ROUTED |
| TIA_RED PD cathode bypass at cathode | ROUTED |
| TIA_RED VBIAS resistor at OPA380 +IN | ROUTED |
| TIA_RED VBIAS capacitor at OPA380 +IN | ROUTED |
| TIA_GREEN photodiode anode to OPA380 -IN | ROUTED |
| TIA_GREEN feedback trimmer at OPA380 -IN | ROUTED |
| TIA_GREEN feedback capacitor at OPA380 -IN | ROUTED |
| TIA_GREEN feedback trimmer at OPA380 OUT | ROUTED |
| TIA_GREEN feedback capacitor at OPA380 OUT | ROUTED |
| TIA_GREEN OPA380 supply decoupling | ROUTED |
| TIA_GREEN PD bias resistor at cathode | ROUTED |
| TIA_GREEN PD cathode bypass at cathode | ROUTED |
| TIA_GREEN VBIAS resistor at OPA380 +IN | ROUTED |
| TIA_GREEN VBIAS capacitor at OPA380 +IN | ROUTED |
| TIA_BLUE photodiode anode to OPA380 -IN | ROUTED |
| TIA_BLUE feedback trimmer at OPA380 -IN | ROUTED |
| TIA_BLUE feedback capacitor at OPA380 -IN | ROUTED |
| TIA_BLUE feedback trimmer at OPA380 OUT | ROUTED |
| TIA_BLUE feedback capacitor at OPA380 OUT | ROUTED |
| TIA_BLUE OPA380 supply decoupling | ROUTED |
| TIA_BLUE PD bias resistor at cathode | ROUTED |
| TIA_BLUE PD cathode bypass at cathode | ROUTED |
| TIA_BLUE VBIAS resistor at OPA380 +IN | ROUTED |
| TIA_BLUE VBIAS capacitor at OPA380 +IN | ROUTED |
| LASER_IR TLV9001 OUT to gate resistor | ROUTED |
| LASER_IR gate resistor to AO3400A gate | ROUTED |
| LASER_IR AO3400A source to sense resistor | ROUTED |
| LASER_IR sense feedback to TLV9001 -IN | ROUTED |
| LASER_IR isolated ISENSE tap at sense resistor | ROUTED |
| LASER_IR TLV9001 supply decoupling | ROUTED |
| LASER_IR PWM input resistor at TLV9001 +IN | ROUTED |
| LASER_IR command limiter at TLV9001 +IN | ROUTED |
| LASER_IR command filter cap at TLV9001 +IN | ROUTED |
| LASER_IR compensation cap at TLV9001 -IN | ROUTED |
| LASER_IR compensation cap at TLV9001 OUT | ROUTED |
| LASER_RED TLV9001 OUT to gate resistor | ROUTED |
| LASER_RED gate resistor to AO3400A gate | ROUTED |
| LASER_RED AO3400A source to sense resistor | ROUTED |
| LASER_RED sense feedback to TLV9001 -IN | ROUTED |
| LASER_RED isolated ISENSE tap at sense resistor | ROUTED |
| LASER_RED TLV9001 supply decoupling | ROUTED |
| LASER_RED PWM input resistor at TLV9001 +IN | ROUTED |
| LASER_RED command limiter at TLV9001 +IN | ROUTED |
| LASER_RED command filter cap at TLV9001 +IN | ROUTED |
| LASER_RED compensation cap at TLV9001 -IN | ROUTED |
| LASER_RED compensation cap at TLV9001 OUT | ROUTED |
| LASER_GREEN TLV9001 OUT to gate resistor | ROUTED |
| LASER_GREEN gate resistor to AO3400A gate | ROUTED |
| LASER_GREEN AO3400A source to sense resistor | ROUTED |
| LASER_GREEN sense feedback to TLV9001 -IN | ROUTED |
| LASER_GREEN isolated ISENSE tap at sense resistor | ROUTED |
| LASER_GREEN TLV9001 supply decoupling | ROUTED |
| LASER_GREEN PWM input resistor at TLV9001 +IN | ROUTED |
| LASER_GREEN command limiter at TLV9001 +IN | ROUTED |
| LASER_GREEN command filter cap at TLV9001 +IN | ROUTED |
| LASER_GREEN compensation cap at TLV9001 -IN | ROUTED |
| LASER_GREEN compensation cap at TLV9001 OUT | ROUTED |
| LASER_BLUE TLV9001 OUT to gate resistor | ROUTED |
| LASER_BLUE gate resistor to AO3400A gate | ROUTED |
| LASER_BLUE AO3400A source to sense resistor | ROUTED |
| LASER_BLUE sense feedback to TLV9001 -IN | ROUTED |
| LASER_BLUE isolated ISENSE tap at sense resistor | ROUTED |
| LASER_BLUE TLV9001 supply decoupling | ROUTED |
| LASER_BLUE PWM input resistor at TLV9001 +IN | ROUTED |
| LASER_BLUE command limiter at TLV9001 +IN | ROUTED |
| LASER_BLUE command filter cap at TLV9001 +IN | ROUTED |
| LASER_BLUE compensation cap at TLV9001 -IN | ROUTED |
| LASER_BLUE compensation cap at TLV9001 OUT | ROUTED |
| MPD_RAW1 direct LD monitor to sense resistor | ROUTED |
| MPD_RAW1 sense resistor to INA input | ROUTED |
| MPD1 ADC resistor to filter capacitor | ROUTED |
| MPD_RAW2 direct LD monitor to sense resistor | ROUTED |
| MPD_RAW2 sense resistor to INA input | ROUTED |
| MPD2 ADC resistor to filter capacitor | ROUTED |
| MPD_RAW3 direct LD monitor to sense resistor | ROUTED |
| MPD_RAW3 sense resistor to INA input | ROUTED |
| MPD3 ADC resistor to filter capacitor | ROUTED |
| MPD_RAW4 spare sense resistor to INA input | ROUTED |
| MPD_AMP4 INA output to ADC resistor | ROUTED |
| MPD4 ADC resistor to filter capacitor | ROUTED |
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

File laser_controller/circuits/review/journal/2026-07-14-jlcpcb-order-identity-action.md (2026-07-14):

# JLCPCB Order Identity — Action Packet (W2026070704037950)

**Date:** 2026-07-14
**Status:** 🔴 OPEN HOLD — action required by an authorized JLCPCB account holder
**Owner action:** contact JLCPCB; this repo cannot resolve it without supplier evidence.

## Bottom line

The 5-board first-article order was **paid on 2026-07-06 15:04** against a package
whose OPA380 `U1–U4` and Bourns `RV5–RV8` **copper footprints were mirrored**. The
mirror was found **the next day (2026-07-07)** by the operator directly from
JLCPCB's assembly preview.

**UPDATE 2026-07-14 (from the 2026-07-07 bench Codex transcript):** the operator
**did re-upload corrected files to the JLCPCB order on 2026-07-07** — this is not
just a design fix. Evidence: (1) the operator directed rebuilding the board
files/BOM/CPL/zip specifically "to send to jlcpcb" (11:29) and again "repackage and
get ready to send to jlcpcb" (13:19); (2) a pasted view of the JLCPCB order page
shows **`laser_controller_gerbers — Automatically saved, last updated on 7 July,
13:54`**, i.e. the files *on the order itself* were updated on 07-07; (3) the
operator was still working in the JLCPCB portal at 18:55 resolving a parts
shortage. So the corrected package almost certainly reached the order.

**The one residual check:** the portal edits spanned the afternoon (13:54 save)
while the fix kept iterating — the final orientation repair committed at 16:15
(`99bc498`) and a further parts fix at 18:55. So confirm the **last** thing saved to
the order was the *final* corrected package (U1–U4 dot at lower-right, `C70` =
`C970665`), not an intermediate. This is now a *verification*, not a likely defect.
Still **do not power any returned board** before a quick physical pin-1 / pad-net
inspection — cheap insurance, not an expectation of failure.

## Timeline

| When (CDT) | Event | Commit |
| --- | --- | --- |
| 2026-07-06 14:17 | Package regenerated ("Fix J7 assembly clearance") | `52c5190` |
| 2026-07-06 15:03 | Uploaded to JLCPCB | — |
| 2026-07-06 15:04 | **Order placed and PAID** (this is the mirrored package) | `52c5190` |
| 2026-07-07 16:15 | OPA380/Bourns **mirror found + repaired**; C70 part swapped; package regenerated | `99bc498` |
| 2026-07-12 | Hold recorded in order journal | — |
| 2026-07-14 | This action packet | — |

## Two package identities (this is the crux)

**A. PAID / SUBMITTED package — commit `52c5190` — MIRRORED, do not trust**

```text
99edd53cbfd12dce3b5175e06c791c4805ac131a8c83f409c281d4962d1f306f  laser_controller_gerbers.zip
1923d2e624c5fecf20f3a804278eac854853a2d5e9b1e9ac31bfbd97530b8c29  laser_controller_jlcpcb_package.zip
0d0de72c72e62a764d51373d87a15c74c038ac83cad23bf5caaeb77b6064c286  laser_controller_bom_jlcpcb.csv
cc2a82c030d8bbb17dc394fd4fdf4b33de54d7cf10f1a0a383278b746caf655d  laser_controller_pos.csv
```

**B. CORRECTED package — commit `99bc498` — validated, NOT proven sent to JLCPCB**

```text
dabe6c81f73fca316be372faec0ddcb27c40db9f1081e2ea1d487c32bf62c71e  laser_controller_gerbers.zip
e87572074f1539b307b883424d7bf2417fc6e85eba7171bc98e36c94f0586496  laser_controller_jlcpcb_package.zip
08d2133a2d9b546849377074f3d8ed939b40db34f803909adadbe438cdd3a992  laser_controller_bom_jlcpcb.csv
268b0fae73f57049280859a070ec6d71502737950f65b45a3f0e6824f986faa4  laser_controller_pos.csv
```

Material differences between A and B:

1. **Copper mirror fix** on `F_Cu`/`B_Cu` for `U1–U4` (OPA380AID SOIC-8, the
   photodiode TIA amplifiers) and `RV5–RV8` (Bourns 3224W feedback trimmers).
2. **BOM part swap** `C70` → JLC `C970665` (22 µF/100 V electrolytic) in the
   corrected package. (The order journal's earlier `C70 → C242011` note is also
   superseded.)

The corrected package passes `run_laser_controller_review.py` (order package **READY**);
first-article/production release is separately BLOCKED on bring-up work, not on the
Gerbers.

## Step 1 — Ask JLCPCB what they actually built (ready to send)

Send from the account that placed the order, via the JLCPCB order page for
`W2026070704037950` (or support chat / order message):

> Subject: Production file confirmation — Work Order W2026070704037950 / Order Y57-2673627A
>
> Hello, for work order **W2026070704037950** (PCB order **Y57-2673627A**, PCBA
> **SMT026070663451-2673627A**, invoice **2673627A2026070704037950**), we need to
> confirm exactly which production files were used to fabricate and assemble the
> boards, because we uploaded a revised package after payment.
>
> Please provide: (1) the exact Gerber, BOM, and CPL/placement files used for
> production (or their checksums), and (2) the final assembly/placement preview
> images you generated for this order. Specifically, on the assembly preview,
> do the **U1, U2, U3, U4** (SOIC-8) package dots sit at the **lower-right board
> corner**? If the boards have shipped, please also send the production/DFM
> report. If they have not yet been fabricated or assembled, please **pause the
> order** so we can confirm or replace the files first. Thank you.

## Step 2 — Decision tree on JLCPCB's answer

- **Boards NOT yet fabricated/assembled** → upload the **corrected package B**
  (`gerbers.zip` `dabe6c81…` + `bom_jlcpcb.csv` `08d2133a…` + `pos.csv` `268b0fae…`),
  re-confirm the U1–U4 dot at the lower-right corner, and this time select
  **"Confirm production file: yes."** Archive the new preview + hashes here.
- **JLCPCB's production files hash-match corrected package B** → the swap happened;
  clear the hold, archive their confirmation, proceed to receipt inspection.
- **JLCPCB's production files hash-match paid package A (or show U1–U4 dot NOT at
  lower-right)** → boards carry the mirrored front-end. Treat U1–U4 / RV5–RV8 as
  defective: either scrap/rework those parts (mirrored dead-bug placement is
  fragile and not production-acceptable) or re-order with package B. Request rework
  credit / re-fab as the invoice terms allow.
- **JLCPCB cannot say** → assume mirrored (package A) until proven otherwise.

## Step 3 — Physical inspection on receipt (before any power)

1. Photograph both sides of all 5 boards before touching power.
2. Under magnification, verify `U1–U4` OPA380 pin-1 / package dot is at the
   **lower-right board corner** (matches corrected geometry). If the dot is at the
   upper-left, the mirrored copper shipped.
3. Verify `RV5–RV8` Bourns 3224W wiper/pad geometry against the corrected pad map
   in `../signoff/2026-07-07-opa380-bourns-orientation-repair-signoff.md`.
4. Continuity-check `PD_ANODE` summing node → OPA380 pin 2 and `VOUTx` → pin 6 on
   one board before powering any.
5. Confirm whether bottom-side `D1–D4` (SFH2201) were assembled; if not, hand-place.
6. Reconcile the outline discrepancy: order page said `173.03 × 71.12 mm`; the
   archived Edge.Cuts measures `173.025 × 61.125 mm`. Confirm the real board size.

## Cross-references

- Order record: [`journal/2026-07-06-jlcpcb-laser-controller-order.md`](2026-07-06-jlcpcb-laser-controller-order.md)
- Mirror repair: [`signoff/2026-07-07-opa380-bourns-orientation-repair-signoff.md`](../signoff/2026-07-07-opa380-bourns-orientation-repair-signoff.md)
- Superseded paid-package signoff: [`signoff/2026-07-05-final-jlcpcb-order-package-signoff.md`](../signoff/2026-07-05-final-jlcpcb-order-package-signoff.md)

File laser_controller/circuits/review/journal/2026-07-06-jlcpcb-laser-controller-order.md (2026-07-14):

# JLCPCB Laser Controller First-Article Order

Date recorded: 2026-07-06

Scope: JLCPCB first-article PCB plus PCBA order for the laser controller.

## Status

- Order placed and paid.
- JLCPCB work order / batch: `W2026070704037950`
- PCB order: `Y57-2673627A`
- PCBA order: `SMT026070663451-2673627A`
- Invoice: `2673627A2026070704037950`
- Invoice date: 2026-07-07
- Gerber file name on JLCPCB: `laser_controller_gerbers_Y57`
- BOM file: `laser_controller_bom_jlcpcb.csv`
- CPL file: `laser_controller_pos.csv`
- Submitted: 2026-07-06 15:03 per JLCPCB order page
- Paid: 2026-07-06 15:04 per JLCPCB order page
- Status at capture: reviewing

### Critical post-order production-file hold — 2026-07-12

The hashes archived below identify the package at commit `52c519...`. The
2026-07-07
[`OPA380/Bourns orientation repair signoff`](../signoff/2026-07-07-opa380-bourns-orientation-repair-signoff.md)
subsequently determined that this package had real mirrored OPA380 `U1–U4` and
Bourns `RV5–RV8` footprints and explicitly says the old package should not be
approved. The regenerated current package has different hashes.

No immutable JLCPCB portal/DFM artifact in this repository proves that the
corrected package replaced the paid submission for `W2026070704037950`.
Therefore the order is on an evidence hold even if the portal later advanced:

1. contact JLCPCB immediately and obtain the exact production Gerber/BOM/CPL or
   their hashes plus the final assembly preview;
2. confirm OPA380 `U1–U4` package dots at the lower-right board corner and verify
   RV5–RV8 physical pad geometry;
3. resolve the `71.12 mm` versus `61.125 mm` outline discrepancy and whether
   bottom-side `D1–D4` assembly was included;
4. if the old files entered production, stop/rework/scrap as appropriate; and
5. do not power returned boards before physical pin-1/pad-net inspection.

This repository cannot claim that the corrected design was fabricated until
that supplier evidence is archived.

Shipping/billing contact details, card details, phone number, email address,
street address, and tax/VAT value are intentionally not copied into git. Refer
to the JLCPCB invoice/order page for those fields.

## Order Contents

- Product: rigid populated printed circuit board
- Quantity: 5 assembled boards
- PCB build time: 3 days
- PCBA build time: 5-6 days
- Shipping method: DHL Express, DDP
- Type of trade: DDP
- Total weight: 1.2 kg
- PCB weight: 0.68 kg
- PCBA weight: 0.52 kg

## PCB Specification Captured From Order

- Base material: FR-4
- Layers: 4
- Delivery format: single PCB
- PCB thickness: 1.6 mm
- PCB color: blue
- Silkscreen: white
- Material type: FR4 TG135
- Surface finish: HASL with lead
- Via covering: plugged
- Outer copper weight: 1 oz
- Inner copper weight: 0.5 oz
- Electrical test: flying probe fully test
- Appearance quality: IPC Class 2 Standard
- Mark on PCB: remove mark
- Minimum via hole size / diameter: 0.3 mm / 0.4-0.45 mm
- Board outline tolerance: +/-0.2 mm regular
- Package box: with JLCPCB logo
- Confirm production file: no
- Shortage preference: require full quantity

The user-copied JLCPCB order text listed dimensions as `173.03 mm x 71.12 mm`.
The local archived package and Edge.Cuts audit for the committed source package
measure `173.025 mm x 61.125 mm`, matching the earlier JLCPCB preview. If the
JLCPCB DFM/review report repeats `71.12 mm`, re-check the production file before
approving any engineering question.

## PCBA Scope

- Assembly service: standard PCBA.
- Assembly side captured from order page: top side.
- JLCPCB PCBA file review captured as paid/reviewing.
- JLCPCB parser state before ordering: BOM and CPL accepted together, 60 parts
  detected, 60 parts confirmed, no unmatched parts, no inventory shortage.
- The order review used the corrected five-column JLCPCB CPL with connector
  origin/rotation corrections for the USB, RJ45, barrel jack, and J7 header
  rows.

Backside optical handling remains a first-article receipt check:

- `D1`-`D4` SFH2201 signal photodiodes are bottom-side SMT footprints. If JLCPCB
  did not include bottom-side assembly in the final DFM, hand-place or rework
  them before optical calibration.
- `LD1`-`LD4` direct laser cans are hand-installed optical parts.

## Cost

- PCB line: USD 37.20
- PCBA line: USD 432.83
- Merchandise total: USD 470.03
- Shipping: USD 51.66
- Subtotal: USD 521.69
- State sales/use tax: USD 44.99
- Customs duties and taxes: USD 164.52
- Grand total: USD 731.20

## Evidence Closure

current quote timestamp: 2026-07-06 15:03 submitted, 2026-07-06 15:04 paid.

accepted C-code: JLCPCB parser accepted the submitted BOM/CPL and confirmed all
60 detected top-side parts with no unmatched row and no inventory shortage at
the captured order quantity.

no automatic substitution: no quote-page automatic substitution was recorded at
order placement. Quote-time replacements had already been intentionally locked
in the BOM before upload (`R41` -> `C22908`, `R42/R44/R46/R48` -> `C103446`,
`C70` -> `C242011`, `J1/J2` -> `C46391`, `J5` -> `C194407`, `J6` -> `C386757`).

order archive: the committed artifacts and hashes below identify the package
used for the placed order.

## Archived Artifacts

Source commit at order record time:

```text
52c5190325bc3a2ad6cdec6fd9e6875b215e729a
```

```text
99edd53cbfd12dce3b5175e06c791c4805ac131a8c83f409c281d4962d1f306f  circuits/laser_controller_gerbers.zip
1923d2e624c5fecf20f3a804278eac854853a2d5e9b1e9ac31bfbd97530b8c29  circuits/laser_controller_jlcpcb_package.zip
0d0de72c72e62a764d51373d87a15c74c038ac83cad23bf5caaeb77b6064c286  circuits/laser_controller_bom_jlcpcb.csv
cc2a82c030d8bbb17dc394fd4fdf4b33de54d7cf10f1a0a383278b746caf655d  circuits/fab/laser_controller_pos.csv
9e6e2266a2cebb7bb652c375bdf4190f4084cacffa63eb1634251269d71d228f  circuits/fab/laser_controller_full_procurement.csv
```

## Captured JLCPCB Preview Images

Top-side JLCPCB placement / board preview captured after order placement:

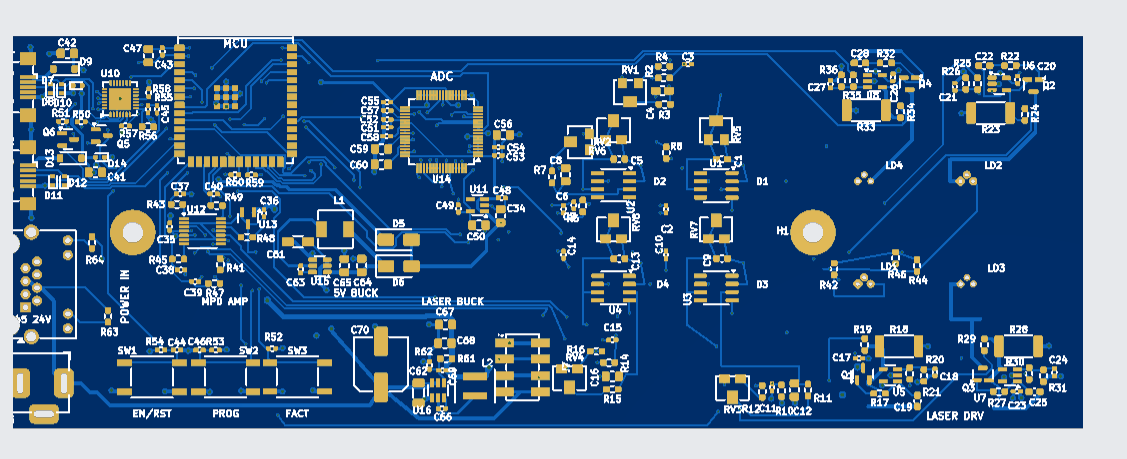
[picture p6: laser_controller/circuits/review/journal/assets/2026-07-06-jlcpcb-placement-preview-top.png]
JLCPCB laser controller top-side placement preview


```text
01eee27b21ea59ea4702960212312023ae7211f63de336fc69c854f794fb369f  circuits/review/journal/assets/2026-07-06-jlcpcb-placement-preview-top.png
```

## Follow-Up On Receipt

- Save JLCPCB DFM/review result once review completes.
- On receipt, photograph both sides before powering.
- Confirm J5/J6/J7 mechanical alignment and connector orientation.
- Confirm whether D1-D4 were assembled; if not, hand-place before optical
  calibration.
- Verify LD1-LD4 can pinout and orientation before soldering laser cans.
- Start bring-up from the first-article power, firmware, laser, and optical
  calibration templates under `circuits/review/calibration/`.

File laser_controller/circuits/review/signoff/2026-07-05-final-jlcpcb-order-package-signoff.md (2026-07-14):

# Final JLCPCB Order Package Signoff

> **Superseded / critical hold (2026-07-12):** the hashes in this signoff bind to
> the pre-repair package. The 2026-07-07 OPA380/Bourns signoff found real mirrored
> U1–U4 and RV5–RV8 footprints and says this old package should not be approved.
> No archived JLCPCB production-file confirmation proves that the corrected
> package replaced the paid submission. See the order journal before accepting
> or powering any returned board.

Date: 2026-07-05; updated 2026-07-06 for J1/J2 USB and J5/J6 THT assembly inclusion

Scope: Current laser-controller fabrication package for JLCPCB PCB plus top-side
SMT assembly and J5/J6 THT connector assembly upload, with only the optical
PD/LD devices on the backside.

## Package Status

`python3 circuits/run_laser_controller_review.py` reports:

- `JLCPCB order package status: READY`
- `First-article/production release status: BLOCKED`
- `DEFERRED: Open first-article/production blockers`

The deferred blockers are calibration, firmware, thermal, protection,
procurement, and measured bring-up work. They do not invalidate the current
Gerber/BOM/POS upload package, but they must be closed before trusting the board
for bench measurements, optical safety behavior, production, or field use.

## Placed First-Article Order

Order placed and paid on 2026-07-06:

- JLCPCB work order / batch: `W2026070704037950`
- PCB order: `Y57-2673627A`
- PCBA order: `SMT026070663451-2673627A`
- Invoice: `2673627A2026070704037950`
- Gerber file name on JLCPCB: `laser_controller_gerbers_Y57`
- BOM/CPL files: `laser_controller_bom_jlcpcb.csv`,
  `laser_controller_pos.csv`
- Quantity: 5 boards
- Assembly side captured from order page: top side
- Grand total: USD 731.20

The order record is archived in
`circuits/review/journal/2026-07-06-jlcpcb-laser-controller-order.md`.
Shipping/billing PII and card details were intentionally left out of git.

## Verification

- `python3 circuits/check_jlcpcb_order_package.py`
  - PASS: 14 Gerber/drill files
  - PASS: package archive includes BOM/POS
  - PASS: 175/175 BOM/POS designators match
  - PASS: J5/J6 are included for THT connector assembly
  - PASS: J7 is `C192300` 2x4 SMD
  - PASS: only PD/LD footprints are bottom-side
  - PASS: PD/laser labels and backside `vivonics` mark are present
- KiCad 10.0.4 hard DRC: PASS, 0 violations, 0 unconnected pads, 0
  schematic-parity errors at error severity.
- KiCad 10.0.4 full DRC: PASS for layout/connectivity, with 36
  footprint/symbol metadata field warnings only.
- Optical-side placement readback: B.Cu footprints are `D1`-`D4` and
  `LD1`-`LD4`; B.Paste footprints are `D1`-`D4` only.
- 3D model coverage: PASS.
- Signal-PD footprint geometry: PASS.
- Laser-diode footprint pinout: PASS.

## Upload Artifacts

- `circuits/laser_controller_jlcpcb_package.zip`
- `circuits/laser_controller_gerbers.zip`
- `circuits/laser_controller_bom_jlcpcb.csv`
- `circuits/fab/laser_controller_pos.csv`
- `circuits/fab/laser_controller_jlcpcb_upload_manifest.md`

`circuits/laser_controller_jlcpcb_package.zip` contains 16 files: front/back
copper, two inner copper layers, paste, silkscreen, mask, Edge.Cuts, Gerber job,
PTH/NPTH drills, JLCPCB BOM, and JLCPCB POS.

The CPL uses the same coordinate frame as the KiCad Gerbers, including negative
Y coordinates. Do not shift it to a board-local `0,0` origin before upload.

For the JLCPCB web flow, upload `laser_controller_gerbers.zip` on the PCB page,
then upload `laser_controller_bom_jlcpcb.csv` and
`circuits/fab/laser_controller_pos.csv` on the PCBA page. The combined
`laser_controller_jlcpcb_package.zip` is a flat transfer/review archive, not the
preferred PCBA BOM/CPL upload.

## PCBA Side Policy

All ICs, passives, trimmers, switches, buck parts, SMD connectors, and the J5/J6
through-hole power connectors are on the front/top side. The only backside SMT
parts intended for JLCPCB placement are `D1`-`D4` (`SFH2201`) if two-sided SMT
assembly is selected. `LD1`-`LD4` direct laser cans remain
hand-installed/mechanically inspected optical parts.

After BOM/CPL upload, the JLCPCB quote should show:

- no unmatched components,
- no CPL processing failure,
- `J1,J2` selected as `C46391` for top-side Mini-B USB assembly,
- `J5` selected as `C194407` for THT/wave/manual connector assembly,
- `J6` selected as `C386757` for THT/wave/manual connector assembly,
- `J7` selected as `C192300`,
- top-side assembly containing the normal SMT population,
- bottom-side assembly, if enabled, containing only `D1`-`D4` `SFH2201`.

If ordering top-side assembly only, remove or deselect `D1`-`D4` in the JLCPCB
PCBA review and hand-place the SFH2201 photodiodes with the laser cans.

## Quote-Time Procurement Notes

The July 5 quote triage replaced the three rows JLCPCB flagged:

- `R42,R44,R46,R48`: `RTT032400FTP`, JLCPCB `C103446`, 240 ohm 0603.
- `R41`: `0603WAF2491T5E`, JLCPCB `C22908`, 2.49 k 0603.
- `C70`: `100CE22FS+P`, JLCPCB `C242011`, 22 uF 100 V SMD electrolytic.

`R41` was moved to `C22908` after JLCPCB reported a shortfall for `C103460`.
`C242011` had enough live stock for a 5-board first-article order but little
margin during the July 5 quote review. If `C70` is short when uploading, do not
change copper or footprints; either select a same-footprint JLCPCB substitute on
the quote page and checkpoint the new C-code, or mark the single row
not-assembled and hand-place that part.

## SHA256

```text
99edd53cbfd12dce3b5175e06c791c4805ac131a8c83f409c281d4962d1f306f  circuits/laser_controller_gerbers.zip
1923d2e624c5fecf20f3a804278eac854853a2d5e9b1e9ac31bfbd97530b8c29  circuits/laser_controller_jlcpcb_package.zip
0d0de72c72e62a764d51373d87a15c74c038ac83cad23bf5caaeb77b6064c286  circuits/laser_controller_bom_jlcpcb.csv
cc2a82c030d8bbb17dc394fd4fdf4b33de54d7cf10f1a0a383278b746caf655d  circuits/fab/laser_controller_pos.csv
9e6e2266a2cebb7bb652c375bdf4190f4084cacffa63eb1634251269d71d228f  circuits/fab/laser_controller_full_procurement.csv
```

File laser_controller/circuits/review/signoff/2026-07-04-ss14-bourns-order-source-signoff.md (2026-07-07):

# SS14 and Bourns 3224W Order/Orientation Signoff

Date: 2026-07-04 CDT

Scope: D5-D6 SS14 OR-ing diodes and RV1-RV8 Bourns 3224W trimmers on
`circuits/laser_controller.kicad_pcb`.

Supersession note: the 2026-07-07 JLCPCB-preview re-audit found this signoff
was insufficient for RV5-RV8 because it checked numeric pad nets but not local
physical footprint geometry. RV5-RV8 were repaired and re-signed in
`circuits/review/signoff/2026-07-07-opa380-bourns-orientation-repair-signoff.md`.
This document remains evidence for D5/D6 SS14 polarity and for the intended
Bourns pin-net roles, but the 2026-07-07 signoff is the controlling physical
Bourns 3224W orientation evidence.

## Source Evidence

- JLCPCB part detail page for C2480 identifies the orderable SMT assembly part
  as MDD(Microdiode Semiconductor) `SS14`, JLCPCB part `C2480`, package
  `SMA(DO-214AC)`, Basic assembly, 40 V / 1 A Schottky diode.
- LCSC C2480 page also identifies the part as MDD(Microdiode Semiconductor)
  `SS14`, package `SMA(DO-214AC)`, key attribute `DIODE SCHOTTKY 40V
  SMA(DO-214AC)`.
- Bourns 3224 datasheet identifies pin `2` as `WIPER`, with pins `1` and `3`
  as the end terminals.
- KiCad stock `Potentiometer_Bourns_3224W_Vertical` footprint is SMD and uses
  pad `2` as the large center pad, with pads `1` and `3` as the end terminals.

## PCB Extraction

Extraction command:

```bash
/usr/bin/python3 - <<'PY'
import pcbnew
board = pcbnew.LoadBoard('circuits/laser_controller.kicad_pcb')
for fp in board.GetFootprints():
    ref = fp.GetReference()
    if ref in ['D5', 'D6'] or ref.startswith('RV'):
        print(ref, fp.GetValue(), fp.GetFPID().GetLibItemName(),
              fp.GetOrientationDegrees(), fp.GetLayerName())
        for pad in sorted(fp.Pads(), key=lambda p: p.GetNumber()):
            print(' ', pad.GetNumber(), pad.GetNetname())
PY
```

Relevant result:

| Ref | Pad 1 | Pad 2 | Pad 3 | Verdict |
|---|---|---|---|---|
| D5 | `VBUS_5V` anode | `+5V` cathode | - | USB VBUS OR-ing polarity is correct. |
| D6 | `/POWER_IO/BUCK_5V` anode | `+5V` cathode | - | Buck 5 V OR-ing polarity is correct. |
| RV1 | `Net-(R4-Pad2)` | `Net-(RV1-W)` | `GND` | Pin 2 is the VBIAS wiper net. |
| RV2 | `Net-(R8-Pad2)` | `Net-(RV2-W)` | `GND` | Pin 2 is the VBIAS wiper net. |
| RV3 | `Net-(R12-Pad2)` | `Net-(RV3-W)` | `GND` | Pin 2 is the VBIAS wiper net. |
| RV4 | `Net-(R16-Pad2)` | `Net-(RV4-W)` | `GND` | Pin 2 is the VBIAS wiper net. |
| RV5 | `Net-(D1-A)` | `VOUT1` | `VOUT1` | Pin 2 wiper is tied to output side. |
| RV6 | `Net-(D2-A)` | `VOUT2` | `VOUT2` | Pin 2 wiper is tied to output side. |
| RV7 | `Net-(D3-A)` | `VOUT3` | `VOUT3` | Pin 2 wiper is tied to output side. |
| RV8 | `Net-(D4-A)` | `VOUT4` | `VOUT4` | Pin 2 wiper is tied to output side. |
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

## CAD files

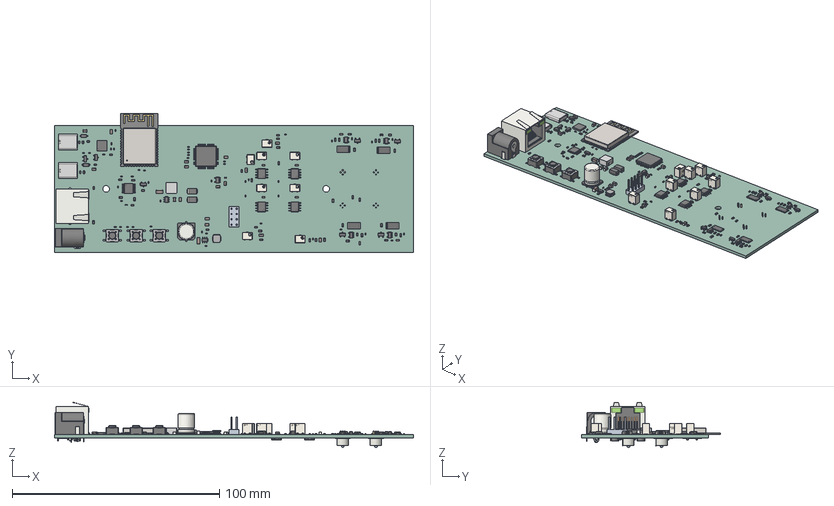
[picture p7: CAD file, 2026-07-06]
laser_controller/circuits/laser_controller.step
173.0 x 66.8 x 21.8 mm
RES-ADJ-SMD_3224W x 8
R_0603_1608Metric x 41
C_0603_1608Metric x 8
D_SOD_523 x 6
C_0805_2012Metric x 16
C_0402_1005Metric x 38
MICRO-USB-SMD_920-462A2021S10101 x 2
D_SOD-123 x 2
SOIC-8_3.9x4.9mm_P1.27mm x 4
D_SMA x 2
C_1206_3216Metric x 2
R_2512_6332Metric x 4
SOT-23 x 7
IND-SMD_L4.0-W4.0-H1.9
TSOT-23-6 x 2
R_0402_1005Metric x 11
IND-SMD_L5.4-W5.2-H3.0
LQFP-64_10x10mm_P0.5mm
QFN-28-1EP_5x5mm_Pitch0.5mm
SOT-23-5 x 5
BarrelJack_Horizontal
C0201_20210301.STEP^C0201_20210301.STEP_Submodel-C0201_part_ DesignRootModel_PCB_ESP32-S3-WROOM-1_V1(2)_PCB_ESP32-S3-WROOM-1_V1 x 14
L0201_20210301.STEP^L0201_20210301.STEP_Submodel-L0201_part_ DesignRootModel_PCB_ESP32-S3-WROOM-1_V1(2)_PCB_ESP32-S3-WROOM-1_V1 x 3
C0402_20210301.STEP^C0402_20210301.STEP_Submodel-C0402_part_ DesignRootModel_PCB_ESP32-S3-WROOM-1_V1(2)_PCB_ESP32-S3-WROOM-1_V1
R0201_20210301.STEP^R0201_20210301.STEP_Submodel-R0201_part_ DesignRootModel_PCB_ESP32-S3-WROOM-1_V1(2)_PCB_ESP32-S3-WROOM-1_V1 x 8
trace_1^Submodel-MINI-ANT-TYPEB_668419613_part_DesignRootModel_PCB_ ESP32-S3-WROOM-1_V1(2)_PCB_ESP32-S3-WROOM-1_V1
DFN1006.STEP^DFN1006.STEP_Submodel-SOD882_part_DesignRootModel_PCB_ ESP32-S3-WROOM-1_V1(2)_PCB_ESP32-S3-WROOM-1_V1
SOP8_rev1_20210308.STEP^SOP8_rev1_20210308.STEP_Submodel-SOP8_1P27_6P6_ part_DesignRootModel_PCB_ESP32-S3-WROOM-1_V1(2)_PCB_ESP32-S3-WROOM-1_V1
XTAL3225_20210301.STEP^XTAL3225_20210301.STEP_Submodel-XTAL3225_part_ DesignRootModel_PCB_ESP32-S3-WROOM-1_V1(2)_PCB_ESP32-S3-WROOM-1_V1
ESP32-S3_20210301.STEP^ESP32-S3_20210301.STEP_Submodel-QFN56_0P4_7_ part_DesignRootModel_PCB_ESP32-S3-WROOM-1_V1(2)_PCB_ESP32-S3-WROOM-1_V1
uid__4-128^DesignRootModel_PCB_ESP32-S3-WROOM-1_V1(2)_PCB_ ESP32-S3-WROOM-1_V1
uid__4-129^DesignRootModel_PCB_ESP32-S3-WROOM-1_V1(2)_PCB_ ESP32-S3-WROOM-1_V1
uid__4-130^DesignRootModel_PCB_ESP32-S3-WROOM-1_V1(2)_PCB_ ESP32-S3-WROOM-1_V1
uid__4-149^DesignRootModel_PCB_ESP32-S3-WROOM-1_V1(2)_PCB_ ESP32-S3-WROOM-1_V1
uid__4-150^DesignRootModel_PCB_ESP32-S3-WROOM-1_V1(2)_PCB_ ESP32-S3-WROOM-1_V1
uid__4-151^DesignRootModel_PCB_ESP32-S3-WROOM-1_V1(2)_PCB_ ESP32-S3-WROOM-1_V1
uid__4-167^DesignRootModel_PCB_ESP32-S3-WROOM-1_V1(2)_PCB_ ESP32-S3-WROOM-1_V1
uid__4-168^DesignRootModel_PCB_ESP32-S3-WROOM-1_V1(2)_PCB_ ESP32-S3-WROOM-1_V1
uid__4-169^DesignRootModel_PCB_ESP32-S3-WROOM-1_V1(2)_PCB_ ESP32-S3-WROOM-1_V1
uid__1-279^DesignRootModel_PCB_ESP32-S3-WROOM-1_V1(2)_PCB_ ESP32-S3-WROOM-1_V1
uid__1-280^DesignRootModel_PCB_ESP32-S3-WROOM-1_V1(2)_PCB_ ESP32-S3-WROOM-1_V1
uid__1-292^DesignRootModel_PCB_ESP32-S3-WROOM-1_V1(2)_PCB_ ESP32-S3-WROOM-1_V1
uid__1-298^DesignRootModel_PCB_ESP32-S3-WROOM-1_V1(2)_PCB_ ESP32-S3-WROOM-1_V1
uid__1-299^DesignRootModel_PCB_ESP32-S3-WROOM-1_V1(2)_PCB_ ESP32-S3-WROOM-1_V1
uid__1-300^DesignRootModel_PCB_ESP32-S3-WROOM-1_V1(2)_PCB_ ESP32-S3-WROOM-1_V1
uid__1-301^DesignRootModel_PCB_ESP32-S3-WROOM-1_V1(2)_PCB_ ESP32-S3-WROOM-1_V1
uid__1-304^DesignRootModel_PCB_ESP32-S3-WROOM-1_V1(2)_PCB_ ESP32-S3-WROOM-1_V1
uid__1-305^DesignRootModel_PCB_ESP32-S3-WROOM-1_V1(2)_PCB_ ESP32-S3-WROOM-1_V1
uid__1-308^DesignRootModel_PCB_ESP32-S3-WROOM-1_V1(2)_PCB_ ESP32-S3-WROOM-1_V1
uid__1-310^DesignRootModel_PCB_ESP32-S3-WROOM-1_V1(2)_PCB_ ESP32-S3-WROOM-1_V1
uid__1-311^DesignRootModel_PCB_ESP32-S3-WROOM-1_V1(2)_PCB_ ESP32-S3-WROOM-1_V1
uid__1-325^DesignRootModel_PCB_ESP32-S3-WROOM-1_V1(2)_PCB_ ESP32-S3-WROOM-1_V1
uid__1-334^DesignRootModel_PCB_ESP32-S3-WROOM-1_V1(2)_PCB_ ESP32-S3-WROOM-1_V1
uid__1-338^DesignRootModel_PCB_ESP32-S3-WROOM-1_V1(2)_PCB_ ESP32-S3-WROOM-1_V1
uid__1-339^DesignRootModel_PCB_ESP32-S3-WROOM-1_V1(2)_PCB_ ESP32-S3-WROOM-1_V1
uid__1-340^DesignRootModel_PCB_ESP32-S3-WROOM-1_V1(2)_PCB_ ESP32-S3-WROOM-1_V1
uid__1-343^DesignRootModel_PCB_ESP32-S3-WROOM-1_V1(2)_PCB_ ESP32-S3-WROOM-1_V1
uid__1-344^DesignRootModel_PCB_ESP32-S3-WROOM-1_V1(2)_PCB_ ESP32-S3-WROOM-1_V1
uid__1-345^DesignRootModel_PCB_ESP32-S3-WROOM-1_V1(2)_PCB_ ESP32-S3-WROOM-1_V1
uid__1-352^DesignRootModel_PCB_ESP32-S3-WROOM-1_V1(2)_PCB_ ESP32-S3-WROOM-1_V1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

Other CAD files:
models/12mm test tube base - 6674298/files/6Tubes.3mf
models/jig/card-grating-holder.stl
models/test-tube-holder/24-tubes.3mf
models/12mm test tube base - 6674298/files/4Tubes.stl
models/jig/laser-controller-housing-mirror.3mf
models/12mm test tube base - 6674298/files/3Tubes.stl
models/jig/lens-holder.3mf
models/12mm test tube base - 6674298/files/2Tubes.stl
models/jig/laser-controller-housing.stl
models/12mm test tube base - 6674298/files/1Tube.stl
models/jig/lens-razor.3mf
models/jig/reactor-cuvette.3mf
models/jig/reactor.3mf
models/jig/jig.3mf
models/jig/electro-photonic-coupler_7mm.3mf
models/jig/electro-photonic-coupler.3mf
models/jig/controller.3mf
models/12mm test tube base - 6674298/files/6Tubes.stl
models/jig/controller.stl
models/jig/electro-photonic-coupler.stl
models/jig/electro-photonic-coupler_7mm.stl
models/jig/jig.blend
models/jig/jig.stl
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

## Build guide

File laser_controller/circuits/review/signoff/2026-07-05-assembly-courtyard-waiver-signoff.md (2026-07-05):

# Assembly Courtyard Waiver Signoff - 2026-07-05

Scope: current `circuits/laser_controller.kicad_pcb` layout and generated
JLCPCB prototype order package.

## Current Evidence

Commands run:

```bash
/usr/bin/python3 circuits/check_kicad_pcbnew_drc_report.py
/usr/bin/python3 circuits/check_courtyard_overlap_triage.py
python3 circuits/check_layout_review_geometry.py
python3 circuits/check_jlcpcb_order_package.py
```

Observed result:

- Headless Pcbnew DRC refills zones in memory and reports 0 unconnected pads.
- Headless Pcbnew DRC reports 0 footprint errors.
- The only native Pcbnew findings are 4 `[courtyards_overlap]` warnings.
- Courtyard triage reports 0 F.Fab/body-box overlaps.
- All 4 courtyard-only warnings are covered by explicit waivers in
  `circuits/review/assembly_clearance_waivers.json`.
- `check_layout_review_geometry.py` passes, including the D4-to-U4 sensitive
  blue-channel geometry referenced by the courtyard waiver.
- `check_jlcpcb_order_package.py` passes for the Gerber/drill archive, flat
  JLCPCB package archive, BOM/POS designator match, J7 C192300 metadata, and
  required board labels.

Reverified after category-1 checkpoint `c3633d5` at
`2026-07-05T06:04:00-05:00`:

```bash
/usr/bin/python3 circuits/check_courtyard_overlap_triage.py
python3 circuits/check_layout_review_geometry.py
```

Observed result: 4 native courtyard warnings, 0 F.Fab/body-box overlaps, 4/4
covered by explicit courtyard-only waivers, and 15 high-risk layout distances
within targets.

## Waived Pairs

- `C62` / `U16`
- `C62` / `C70`
- `U4` / `D4`
- `C61` / `L1`

## Remaining Manual Review

This signoff accepts the current courtyard-only warnings for controlled
first-article ordering. It does not replace JLCPCB's quote/assembly viewer,
native KiCad schematic ERC/parity, physical part fit inspection, or re-running
the courtyard triage after any placement, footprint, package, or selected-part
change.

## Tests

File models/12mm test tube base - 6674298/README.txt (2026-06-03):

12mm test tube base by Remi-Rafael on Thingiverse: https://www.thingiverse.com/thing:6674298

Summary:
This design is a series of 12mm test tube holders. It is designed to be a snug fit to hold the tube even if it falls down (nevertheless its 4 side legs gives it a very good stability). If you prefer the fit to be looser or if your printer has large tolerances (more than 0.3mm) you should  scale the part to 102-104%.It can be printed without supports.

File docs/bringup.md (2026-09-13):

# Laser-controller bring-up and green-channel hold

**Last updated:** 2026-07-30  
**Board:** assembled ESP32-S3 laser controller `ac:27:6e:ca:0c:e4`  
**Firmware:** `0.3.4-dashboard`, running from `ota_0`  
**Green disposition:** **HOLD LIFTED 2026-08-07** — the hold recorded below was reviewed and refuted in `docs/program/GREEN_CHANNEL_HOLD_REVIEW_2026-08-07.md` (main repository); August–September campaigns ran green from the second controller board at `192.168.1.179`. The first-article loop measurements below remain a dated record; the AVCC rail margin, the covered dark test, and two unexplained latch-on events are still open (`docs/program/LASER_CONTROLLER.md`).

This note is the bench-side electrical bring-up record. Optical geometry,
printed-mask tolerances, and diffraction metrics are owned by
`vivonics/docs/program/BENCH_RUNBOOK.md`; pass thresholds are owned by
`vivonics/docs/ARCHITECTURE.md` §8.

## Immediate safety state

The controller and dashboard finish every check with all commanded duties at
zero. That is not yet a validated physical green shutoff: a green spot remains
visible in the live camera when the green command, controller state, and all
reported duties are zero.

- Keep the beam enclosed and terminated.
- Do not use apparent brightness as a power measurement.
- Do not run Green at full command until the feedback divider, current loop,
  and optical off state pass the checks below.
- Perform unpowered continuity/resistance checks before powered node probing.
- Use wavelength-appropriate eyewear and the lowest useful command for powered
  checks.

## Green control chain

```text
ESP32 GPIO12, 10 kHz PWM
  -> R30 10 kOhm
  -> CMD_FILTER / U7 pin 3 (+)
       |-> R31 3 kOhm to GND
       `-> C24 1 uF to GND
  -> U7 TLV9001 pin 1
  -> R27 1 kOhm
  -> Q3 AO3400A gate
  -> Q3 source / FB / top of R28 10 Ohm
  -> U7 pin 4 (-)
  -> R29 1 kOhm
  -> ISENSE3 telemetry
```

The command divider predicts `0.7615 V` at full PWM and approximately
`76.2 mA` through the `10 Ohm` sense resistor. Its small-signal time constant is
`(R30 || R31) * C24 = 2.31 ms`, or about `69 Hz`. The 10 kHz PWM is therefore
filtered, but this is an electrical current loop, not an optical automatic
power-control loop. The source monitor is telemetry only in the present
firmware.

## Confirmed errors, likely risks, and open assumptions

### Confirmed errors

1. The previous firmware forced all outputs off and re-armed on every nonzero
   slider update. That discharged the command filter and caused visible update
   flicker. Firmware `0.3.4-dashboard` updates an already-latched output in
   place.
2. The previous `/bench` slider effect could omit an all-off request when the
   last armed channel reached zero, or lose the last update while a prior
   request was loading. The live dashboard now serializes and coalesces
   commands; a positive slider value auto-arms that channel and zero disarms it
   and sends the zero setpoint.
3. The assembled Green channel emits visible light at commanded off.
4. Green current-sense and equipped source-monitor telemetry remain exactly
   `0 mV` during visible Green emission. The existing build record also reports
   U7 pin 3 at `1.2 V`, U7 pin 4 at `0 V`, and U12 monitor outputs at `0 V`
   during a full-command IR+Green probe. Green overcurrent protection and
   optical monitoring therefore cannot be credited.

### Likely risks

- An open or misassembled feedback path between Q3 source/R28 and U7 pin 4 can
  leave U7 operating open-loop. Input offset can then drive or chatter Q3 even
  when the nominal command is zero.
- If U7 and FB are low at off but Green still emits, Q3 may be shorted/leaking
  or the laser cathode may have an unintended return path.
- The previously measured `1.2 V` at U7 pin 3 is above the `0.7615 V` predicted
  by the captured `R30=10 kOhm`, `R31=3 kOhm` divider. Installed values, node
  identity, and meter reference must be checked before any high command.
- The board has no independent digital hard-disable element in series with the
  laser supply or gate path. Software-low alone cannot guarantee physical off
  if the analog loop fails.

### Open assumptions

- The visible spot in the declared off screenshot is direct Green LD emission,
  not fluorescence or a second green source. Confirm by disconnecting Green LD
  power with all commands off.
- R28 is installed as `10 Ohm`, R30 as `10 kOhm`, and R31 as `3 kOhm`.
- The camera exposure/white-balance path was stable enough for relative
  frame-to-frame comparisons. It is not calibrated optical-power evidence.

## 2026-07-30 live evidence

| Check | Result | Disposition |
| --- | --- | --- |
| Firmware host suite | sanitizer-enabled suite passed | Pass |
| ESP-IDF target build | pinned ESP-IDF `v5.5.4`; 957,264-byte image | Pass |
| OTA identity | `0.3.4-dashboard`, SHA-256 `0a16303696063fccba7ebe3f36d10b4ded08fd04415cfe8b4d19aeabab6f1f7a` | Pass |
| Boot safe state | `faultMask=0`, ready-lasers-off, duties `[0,0,0,0]` | Logical pass only |
| Slider semantics | Green `0 -> 1` auto-armed; `1 -> 0` disarmed and sent all-off | Pass |
| UI-to-controller confirmation | low-on about `452 ms`; off about `295 ms` | Pass against provisional `500 ms` gate |
| Live update continuity | 56 active telemetry samples across 16 increasing commands; 0 inactive samples inside the active interval | Pass |
| Fine-control range exercised | UI `1..16` mapped monotonically to `4..63 permille` | Pass for command path |
| Settled camera stability | prior 40-frame blocks at direct duties `1,2,4,8,16 permille` had green-mean CV `0.25–0.58%` | Relative pass only |
| Controller faults during sweep | fault mask remained `0` | Pass |
| Green current sense while active | `0 mV` for every active sample | **Fail** |
| Green source monitor while active | `0 mV` for every active sample | **Fail** |
| Physical off | visible green spot remains after confirmed all-off | **Fail** |

The UI remains an 8-bit `0..255` experiment interface. Its smallest nonzero
step maps to about `4 permille` (`0.4%`) at the controller. The controller
protocol itself supports integer `1..1000 permille` (`0.1%`) commands. Do not
interpret either resolution as achieved optical-power resolution until the
analog loop and monitor path are repaired.

## Green probe sequence

Record the meter model, range, ground point, board supply, command, and every
measured value. Do not increase the command if any preceding condition fails.

| Step | State | Probe | Expected result | Interpretation if it fails |
| --- | --- | --- | --- | --- |
| 1 | Power removed | R28 end-to-end | `10 Ohm` within component tolerance | Wrong/open sense resistor |
| 2 | Power removed | Q3 source/R28 top to U7 pin 4 | continuity, near `0 Ohm` trace resistance | Open FB interconnect or solder joint |
| 3 | Power removed | R30 and R31 | `10 kOhm` and `3 kOhm` within tolerance | Wrong population explains command scaling |
| 4 | Commanded off | GPIO12 to GND | logic low, target `<0.2 V` | MCU/output mux is not actually low |
| 5 | Commanded off | U7 pin 3 / CMD_FILTER | target `<5 mV` after settling | Divider/filter leakage or wrong PWM polarity |
| 6 | Commanded off | U7 pin 4 / FB and R28 top | target `<5 mV` | Unintended current or broken reference |
| 7 | Commanded off | U7 pin 1, then Q3 gate | low enough to cut Q3 off; record actual value | U7 rails high/open-loop if FB is open |
| 8 | UI Green level `4` only | U7 pin 3 | about `12.2 mV` (`16 permille`) | Command divider or installed values differ |
| 9 | Same low command | U7 pin 4 / R28 top | tracks pin 3; about `12.2 mV` | Current loop is not closed |
| 10 | Same low command | inferred R28 current | about `1.22 mA` from `V/R` | Do not trust telemetry until it agrees |

Decision tree:

- U7 pin 3 low at off, U7 pin 4 low, but U7 output/gate high: repair or replace
  U7 and verify FB continuity.
- Gate low at off but Green remains visible: isolate Q3 and the LD return path;
  check Q3 for drain-source leakage/short.
- The spot disappears when Green LD supply is physically disconnected:
  confirms direct Green emission and rejects camera-only explanations.
- Do not proceed to optical stability testing until current sense is nonzero
  and proportional at a bounded low command, source monitor responds, and off
  is below the measurement floor.

## Acceptance metrics after repair

These are initial engineering gates, not production specifications.

| Metric | Initial acceptance |
| --- | --- |
| Physical off leakage | below calibrated power-meter detection and below camera dark background plus `5 sigma` |
| Command continuity | no zero/off telemetry sample between adjacent nonzero updates |
| UI command confirmation | `<=500 ms` from slider input to confirmed telemetry |
| Minimum command | controller `1 permille` produces a repeatable response or is explicitly declared below the usable floor |
| Low-level monotonicity | each declared level exceeds the prior level by `>=3 sigma` over repeated captures |
| Short-term source-normalized power | CV `<=1%` in each settled 10 s block |
| Ten-minute drift | `<=1%` after declared warm-up |
| Frame-scale flicker | source-normalized frame CV `<=1%`, peak-to-peak `<=3%`, no unexplained spectral line |
| Current-loop agreement | R28 meter current and calibrated ISENSE3 agree within `+/-5%` initially |
| Source-monitor repeatability | CV `<=1%` at a fixed command; nonzero response above `5 sigma` noise |
| Power-versus-command fit | monotonic usable region with residuals `<=2%` of full scale after calibration |

A calibrated optical power meter and a working source-monitor path are required
to call optical power “rock solid.” The current camera result only shows that
settled image intensity was stable over short blocks.

## Required board revision for fail-safe off

After repairing the first article, add an independent hardware enable in a
future revision: a load switch, laser-rail switch, or gate clamp controlled by
a separate fail-safe signal and default-off pulldown. The safety path must be
able to force zero optical output even if U7 rails or the current-feedback trace
opens. Verify it with a deliberately opened feedback loop and with MCU reset.

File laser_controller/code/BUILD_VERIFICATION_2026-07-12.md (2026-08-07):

# Laser-Controller Firmware Build Verification

**Originally verified 2026-07-12; repeated for the original three profiles on
2026-07-20 and from the relocated bench package on 2026-07-21. The dashboard
profile was built and verified on the assembled board on 2026-07-21.**

## Outcome

- Host decoder/safety suite: **PASS** under `-Wall -Wextra -Werror -Wpedantic`
  plus AddressSanitizer and UndefinedBehaviorSanitizer.
- ESP32-S3 clean container builds: **PASS** twice consecutively for the normal,
  board-validation, and finite-pulse laser-test profiles.
- Post-dashboard regression builds: **PASS** for normal, board-validation,
  laser-test, and dashboard profiles using the same pinned container.
- Reproducibility: bootloader, partition table, application binary, and
  application ELF were byte-identical across the two clean builds.
- Current application sizes: normal `0x324f0`, validation `0x32590`, laser-test
  `0x41650`, and dashboard `0xe9a40` bytes. The dashboard image leaves 54% of
  each 2 MiB OTA slot free.
- Build-log scan: no compiler `warning:`, `error:`, or dubious-ownership message.
- The dashboard profile intentionally includes Wi-Fi, NVS, HTTP server, JSON,
  and application-update components. Bluetooth remains disabled.

## Pinned toolchain

- ESP-IDF: `v5.5.4`
- Official image OCI index:
  `docker.io/espressif/idf@sha256:b9f2d6ea1c19e0c9f7959bdb74a9e3c775642f9d0f3b841937c5fa3363db892b`
- Resolved amd64 manifest:
  `sha256:116f0526dfc87e764785370e59b88822e02cf4f9e1edd953cad5ed2d02672023`
- Target/compiler: `esp32s3`, Xtensa GCC `14.2.0_20260121`

## Locked generated configuration

```text
CONFIG_IDF_TARGET="esp32s3"
CONFIG_ESPTOOLPY_FLASHSIZE="16MB"
CONFIG_FREERTOS_HZ=1000
CONFIG_LC_AD7606_SCLK_HZ=10000000
CONFIG_LC_AD7606_SAMPLE_RATE_HZ=1000
CONFIG_LC_AD7606_BUSY_TIMEOUT_US=100
CONFIG_LC_AD7606_LOG_EVERY_N=0
CONFIG_APP_PROJECT_VER="0.1.0-bringup"
CONFIG_APP_COMPILE_TIME_DATE=n
CONFIG_BOOTLOADER_COMPILE_TIME_DATE=n
```

Flash mode is DIO at 80 MHz. Offsets are bootloader `0x0`, partition table
`0x8000`, and application `0x10000`.

## Repeated-build hashes

```text
dc2676e87a93b03d1c243e6477de0d3bbec30c135eb593b4a1062bae33f54404  bootloader/bootloader.bin
7f00b6c042a89b15b0cac534f82ed988caf29278ff5700b0c511eb1b5bb7c820  partition_table/partition-table.bin
81363ea8dae923ca31142f65ae2ed65d39d3560c586702d2191c0c0149c19b64  vivonics_laser_controller.bin
3d46ea6635d126f8a5c1dd6a3394a6a82f106fb1a76d0c9c43fcd330c725df5e  vivonics_laser_controller.elf
```

Reproduce with:

```bash
laser_controller/code/run-host-tests.sh
laser_controller/code/build-container.sh
```

## Board-validation logging profile

The injection fixture uses a separate artifact with `50 sample/s`, every-sample
UART logging, and version `0.1.0-board-validation`. It retains the same safety
logic and timing-overrun latch but is not interchangeable with the default 1 kSPS
artifact. Two clean validation-profile builds also matched byte-for-byte:

```text
dc2676e87a93b03d1c243e6477de0d3bbec30c135eb593b4a1062bae33f54404  bootloader/bootloader.bin
7f00b6c042a89b15b0cac534f82ed988caf29278ff5700b0c511eb1b5bb7c820  partition_table/partition-table.bin
ed7b8f00ee94b7e4317689ccbd80f5685979d5483638329bd92bdad4d0e0ee08  vivonics_laser_controller.bin
a502d9d521a991bd4976c77bcc73dbac9ec2021a4d93dfbc768480a076a106b5  vivonics_laser_controller.elf
```

Build it with:

```bash
laser_controller/code/build-validation-container.sh
```

Attach the flashed profile, application hash, device identity, and complete boot
metadata to every calibration capture.

## Local laser-test profile

The separately selected `0.1.0-laser-test` profile preserves the AD7606 fault
gate and adds local `STATUS`, `OFF`, `ON`, and bounded `PULSE` commands for
controlled first-article measurements. A valid local USB-serial command is the
test-profile arm request; the physical `FACT` input is not required. `PULSE` is
limited to `20..900 ms`; `ON` remains active until `OFF`, reset, an ADC/telemetry
fault, or overcurrent. Every canonical combination of IR, Red, Green, and Blue
is supported, with `ALL` as an alias for all four. Normal and board-validation
builds keep this option disabled. The current application size is `0x41230`
bytes (`266,800` bytes), leaving `75%` of the 1 MiB app partition free. The
current regression artifact is:

```text
1fbe26e0370b5414e4d6da0af676d9eb87782d7636b233a46087ebb5152e303d  vivonics_laser_controller.bin
```

The earlier two-build reproducibility evidence was:

```text
dc2676e87a93b03d1c243e6477de0d3bbec30c135eb593b4a1062bae33f54404  bootloader/bootloader.bin
7f00b6c042a89b15b0cac534f82ed988caf29278ff5700b0c511eb1b5bb7c820  partition_table/partition-table.bin
6683c6cfe96b20aa03f9b381577acddb9109236f79cd71a88e9cc8875be1daa7  vivonics_laser_controller.bin
26837c0b46176d37c761d8b1bf26d496b28419fe60ee68bc9f06e12f4c5ec3d8  vivonics_laser_controller.elf
```

Build it with:

```bash
laser_controller/code/build-laser-test-container.sh
```

## Dashboard, live-device, and OTA verification

The `0.3.2-dashboard` profile is selected by
`sdkconfig.dashboard.defaults` and built with:

```bash
laser_controller/code/build-dashboard-container.sh
```

The verified application artifact deployed on 2026-07-21 is:

```text
0e0edd67d4961220d849c8dee8125f5994994548b7d4fa74d63004ccc15c7979  vivonics_laser_controller.bin
```

Assembled-board verification on ESP32-S3 `ac:27:6e:ca:0c:e4`:

- full initial flash over built-in USB-JTAG with no `FACT` hold;
- boot from `ota_0`, ADC ready, fault mask zero, outputs OFF;
- WPA2 provisioning AP `VIVONICS-LASER-CA0CE4` and station join to the bench
  LAN;
- live `50 Hz` AD7606 telemetry and responsive desktop/mobile UI with no
  browser console or layout failures;
- simultaneous IR + Green `1000` permille UI control, removal of IR while Green
  remained active, and final verified All-Off;
- independent API duties of IR `700` permille and Green `400` permille, reported
  with channel mask `5` and `sharedDuty: false`;
- IR current telemetry of `365 mV`/approximately `36.5 mA` at full command and
  `246 mV`/approximately `24.6 mA` at 70% command;
- live four-channel AD7606 readings near `0.96`, `1.10`, `1.13`, and `1.12 V`;
- raw HTTP OTA upload of the hash above to `ota_1`, reboot into
  `0.3.2-dashboard`, and final OTA state `valid` after the rollback gate;
- five outputs-off sensing-pin self-tests through
  `POST /api/diagnostics/sensing-pins`; every ISENSE1–4 and MPD1–4 ADC input
  moved repeatably from raw zero to raw `51..55` (`45..50 mV`) under its weak
  internal pull-up and returned to zero under pull-down, with fault mask zero
  and all outputs remaining off.
- live desktop/mobile browser smoke on `0.3.2-dashboard`, including the new
  Dashboard sensing-test control, eight rendered input rows, no browser errors
  or viewport overflow, final All-Off, and fault mask zero.

The live smoke exposed and then verified the fix for a request-lifetime defect
that corrupted the logged target name after a laser command. The reusable
checks are `tests/dashboard-ui-smoke.js` and
`tests/dashboard-live-smoke.js`.

Green current sense and all equipped source-monitor readings remained raw zero
during the live output samples. The API and UI now label those active paths
`no-response`, set `sensingDegraded: true`, make `/api/health` unhealthy, and
state that the values are not hidden or simulated. This is recorded as an
unresolved physical sensing-path issue rather than treated as successful
current/monitor validation. The warning is diagnostic only; it is not a
fail-shutoff latch. Consequently Green overcurrent protection cannot be
credited until the current-sense path is repaired.

### 2026-07-26 active-output watchdog follow-up

During a simultaneous IR + Green physical probe, the last sample snapshot
stopped advancing while the HTTP task remained responsive. Repeated
`POST /api/lasers/off` requests were acknowledged and queued but could not be
consumed by the stalled acquisition/control task. The board was recovered by a
same-image OTA reboot, which restored the safe-low boot state.

`0.3.3-dashboard` adds a separate priority-8 output watchdog. It reads the
published snapshot every `50 ms` and calls `esp_restart()` if any output is
active and the control sample age exceeds `500 ms`. The timeout predicate is a
host-tested pure function, including inactive, exact-boundary, expired,
backwards-clock, and invalid-threshold cases.

The verified application artifact is:

```text
bff1fcaccee2aa41d4a81704914ab84b48448b4959f6b8b487c28dbfc0eaad07  vivonics_laser_controller.bin
```

Verification passed:

- sanitizer-enabled host tests;
- pinned ESP-IDF `v5.5.4` target build, `957,440` application bytes;
- HTTP OTA to `ota_1`, rollback state `valid`, version
  `0.3.3-dashboard`, and fault mask zero;
- live sample index `2039` to `2100` in one second with outputs OFF;
- desktop/mobile live dashboard smoke, no output exercise, final sample index
  `5711`, fault mask zero, and all outputs OFF.

The assembled-board expired-watchdog branch has not been deliberately
fault-injected. The Green-driver and source-monitor analog faults remain open:
with IR and Green commanded at full duty, U7 pin 3 measured `1.2 V`, U7 pin 4
measured `0 V`, and U12 outputs on pins 1 and 8 both measured `0 V`. U13 held
the intended `5.0 V` bias difference (`9.8 V` on pin 1 and `4.8 V` on pins 2
and 3), so the shared source-monitor bias generator is operating.

## Claim boundary

These results prove source compilation, host decoder/safety behavior, pinned
configuration, artifact generation, initial USB-JTAG deployment, live web/ADC
operation, a brief IR/Green control path, and one complete OTA slot transition.
They do **not** prove absolute ADC accuracy or channel order, calibrated optical
power, Green current/monitor sensing, sustained wireless/regulator thermal
behavior, brownout behavior, or physical laser fail-shutoff. Those remain
first-article evidence gates.

## 2026-07-30 gap-free Green-control follow-up

The deployed `0.3.4-dashboard` image adds gap-free reconfiguration for an
already-active latched output and retains the full force-off/arm sequence for
the first nonzero command. It also corrects the transition from direct GPIO
full-duty mode back to LEDC PWM.

```text
0a16303696063fccba7ebe3f36d10b4ded08fd04415cfe8b4d19aeabab6f1f7a  vivonics_laser_controller.bin
```

The pinned ESP-IDF `v5.5.4` target build produced a `957,264` byte application.
OTA booted `0.3.4-dashboard` from `ota_0`, was marked valid, and returned with
fault mask zero and all duties off.

Live `/bench` exercise of 16 increasing Green commands produced 56 controller
telemetry samples inside the active interval with no unintended inactive sample
between nonzero updates. The observed duties were monotonically increasing from
`4` to `63` permille. Final UI zero was confirmed as controller inactive with
duties `[0,0,0,0]`.

This firmware evidence does not close the Green hardware defects. Green
current-sense and source-monitor readings stayed at `0 mV` while the camera
showed Green emission, and a visible Green spot remained after confirmed
all-off. The channel is on hold pending the probe and repair sequence in
`bench/docs/bringup.md`.

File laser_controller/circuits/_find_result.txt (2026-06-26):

2924:    (pin "12" (uuid 95e022f1-d16d-497b-84a0-3fce886a6242))
2930:    (pin "18" (uuid 4eb847ee-4dcf-4f7e-a007-c720eeb28402))
2931:    (pin "19" (uuid 1830af64-f8bc-400d-b3cf-db5eacc9714b))
2933:    (pin "20" (uuid 08714f8d-285d-4902-9fe4-17593e4969b7))
2944:    (pin "4" (uuid 5568a7ba-fa35-4fa7-be32-443cda874d68))
2945:    (pin "5" (uuid 96f4b0ec-3783-4e76-be56-94cfb2ddd0e9))
2946:    (pin "6" (uuid 46edfd14-e51c-4fc7-9bdb-e8e42c512270))
2947:    (pin "7" (uuid 2c39a2e1-bb67-43e1-88a1-09fa5c00a005))
2948:    (pin "8" (uuid 7cd76b3e-64f8-4c35-8480-8cba2d84fc21))
3149:    (pin "12" (uuid 4ebb40e6-ba09-42c3-b47b-727bdb0ba042))
3155:    (pin "18" (uuid 07b8de48-73e8-4bdd-99ee-6dc971f4c252))
3156:    (pin "19" (uuid 8b4fa425-caea-457d-b499-6eecc8417839))
3158:    (pin "20" (uuid 046f4f3c-c457-463f-8f20-09884aa28536))
3179:    (pin "4" (uuid f9bf2724-5c0e-4234-af08-a52fa7f2f7f1))
3182:    (pin "5" (uuid f66fd9e9-31ac-4a46-a3a1-ddb36eca00a1))
3183:    (pin "6" (uuid 324aed4e-78a2-4eea-abd8-6f5a176a81e6))
3184:    (pin "7" (uuid 8852b341-df77-44a2-ba7e-e527863aecb0))
3185:    (pin "8" (uuid bd81be4f-aea6-4c21-917e-d09f15f1233b))
3431:    (pin "4" (uuid 56b6e343-895b-4ab0-93bc-c6131506bad1))
3432:    (pin "5" (uuid 976cbe8b-bcf5-4a71-bed7-e33c59be8ffe))
3635:    (pin "4" (uuid c52a47fa-3fb8-42cc-bab8-b41627749267))
3636:    (pin "5" (uuid 94250fc2-a48b-4c09-8561-d61b34e08cab))

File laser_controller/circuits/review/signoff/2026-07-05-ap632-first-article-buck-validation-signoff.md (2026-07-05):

# AP632 First-Article Buck Validation Signoff - 2026-07-05

## Scope

This signoff accepts the AP63205 `/POWER_IO/BUCK_5V` rail and AP63200
`LASER_V+` rail for controlled first-article bring-up only. It does not release
production 24 V input protection, RJ45 power injection, hot-plug operation, or
unmeasured buck ripple/transient/temperature behavior.

## Accepted First-Article Configuration

- Follow `2026-07-05-vin24-bench-input-signoff.md`: J5 barrel input only,
  24.0 V, external current limit no higher than 300 mA, RJ45 power disabled,
  verified center-positive polarity, and no hot-plug.
- Verify `/POWER_IO/BUCK_5V`, post-OR `+5V`, and `LASER_V+` before enabling
  firmware, lasers, or optical measurements.
- Treat `LASER_V+` as a 9.3 V-class rail and rerun the laser-current and buck
  budget checks before changing the AP63200 feedback network or laser load.
- Measure startup overshoot, steady ripple, and load-step transient on
  `/POWER_IO/BUCK_5V`, post-OR `+5V`, and `LASER_V+` with a short probe ground.
- Measure U15, U16, L1, L2, D6, C64-C65, and C67-C68 temperature during
  steady first-article load.
- Do not run all laser channels at maximum command until `LASER_V+` ripple,
  buck temperature, and laser driver temperature are measured together.
- Rerun `check_buck_input_power_budget.py` before changing the input voltage,
  rail loads, output capacitors, inductors, laser current limits, or `LASER_V+`
  setpoint.

## Remaining Risk

This signoff is enough to order and perform controlled first-article buck
bring-up with external current limiting. It does not close production input protection, adapter/RJ45 harness rating, reverse-polarity protection,
transient/TVS protection, hot-plug behavior, measured ripple/transient/stability
data, or measured temperature data.

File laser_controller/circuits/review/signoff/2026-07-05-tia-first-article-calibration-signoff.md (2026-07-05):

# TIA Readout First-Article Calibration Signoff - 2026-07-05

## Scope

This signoff accepts the current SFH2201/OPA380/AD7606 signal-photodiode path
for controlled first-article calibration. It does not release production
measurement use until the real Vivonics optical photocurrent range, ambient
shielding, trim state, and ADC scaling are measured.

## Accepted First-Article Configuration

- Treat the current 2 Mohm feedback trim as a high-sensitivity, low-current
  bench range.
- Start with VBIAS target 1.5 V and record the actual VBIAS for each channel.
- Keep the SFH2201 detectors covered or optically shielded during dark-offset
  capture.
- Limit ambient light before enabling lasers; the SFH2201 1000 lx example is an
  expected saturation case at 2 Mohm feedback.
- Calibrate `VOUT1..4` one channel at a time with a known electrical current injection or a calibrated optical input at the SFH2201.
- Record RF/trim state, VBIAS, dark ADC counts, response slope, noise floor,
  saturation threshold, ambient condition, and known input level for each
  channel.
- Confirm AD7606 +/-5 V scaling for `VOUT1..4` before trusting counts as
  calibrated voltage.
- Firmware must flag saturation, out-of-range counts, dark-offset drift, and
  any trim/calibration mismatch before reporting production measurements.

## Remaining Risk

This signoff is enough to order and perform controlled first-article TIA
readout calibration. It does not close production measurement release, ambient
shielding, optical-path calibration, noise/stability proof, firmware
implementation, or the final RF/VBIAS setting for field use.

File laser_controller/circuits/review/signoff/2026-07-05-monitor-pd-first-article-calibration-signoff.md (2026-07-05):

# Monitor-PD First-Article Calibration Signoff - 2026-07-05

## Scope

This signoff accepts the current INA4180/LM4040 monitor-PD front end for
controlled first-article bring-up. It does not release production APC,
normalization, or optical-safety behavior until calibration data exists for the
received laser cans and bench optics.

## Accepted First-Article Configuration

- `LD1` D7805I, `LD2` D6505I, and `LD3` PLT5 520EB_P are the only selected
  monitor-capable sources.
- `LD4` PLT5 450GB has no monitor photodiode; treat `MPD_RAW4` / `MPD4` as spare/open, not blue-source telemetry.
- Use MPD telemetry only after calibrating laser current -> MPD ADC counts ->
  external optical power meter for each monitor-capable source.
- Keep the analog current loop and firmware current clamps as the hard safety
  limit. Monitor-PD telemetry must not raise current above the per-channel
  clamps.
- Calibrate one source at a time at minimum firmware duty cycle and minimum
  command before increasing setpoint.
- Record dark/off ADC counts, response slope, saturation threshold, firmware
  setpoint, and external optical-power reading for each monitor-capable source.
- Firmware must fail shutoff or inhibit the source if the monitor path is open,
  shorted, saturated, current rises without monitor response, or the requested
  optical setpoint would exceed the current clamp.

## Remaining Risk

This signoff is enough to order and perform controlled first-article monitor-PD
bring-up with an external optical meter. It does not close production APC,
normalization, or optical-safety release. It also does not close physical
orientation inspection, diode substitution review, firmware implementation,
ambient-light coupling, or measured calibration data.

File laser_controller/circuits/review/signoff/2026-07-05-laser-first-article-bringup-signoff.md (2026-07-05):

# 2026-07-05 Laser First-Article Bring-Up Signoff

Scope: LD1-LD4 first-article laser bring-up on the current JLCPCB bench board.

This signoff accepts the electrical current-limit design for controlled
first-article bring-up only. It does not close optical safety, driver/sense
temperature measurement, optical output calibration, firmware clamp validation,
loop transient behavior, or production laser release.

## Accepted Bring-Up Configuration

- Use appropriate wavelength-rated laser safety eyewear and an enclosed beam stop before any LD1-LD4 channel is energized.
- Inspect each received laser can against the 2026-07-04 MPN/footprint pin table
  before soldering.
- Bring up one laser channel at a time.
- Start each channel at minimum firmware duty cycle and minimum command.
- Keep firmware current and duty-cycle clamps at or below the per-channel analog
  command limits: IR 38.0 mA, red 23.0 mA, green 76.2 mA, blue 105.5 mA.
- Verify the shared `LASER_V+` rail before enabling any channel; the current
  checked reference is the 9.3 V-class rail.
- Measure driver/sense-resistor temperature during bring-up for every channel.
- Measure optical output with an external optical power meter for every channel.
- Do not run all four colors continuously at maximum command without thermal
  measurement.

## Current Evidence

- `check_laser_current_budget.py --policy selected-diodes-typ-9v3` passes.
- `check_laser_current_budget.py --policy selected-diodes-max-9v3` passes.
- `check_laser_current_budget.py --policy selected-diodes-hardware-clamp-9v3`
  passes for the per-channel analog command limiter high-current corner.
- `check_laser_driver_control_loop.py --policy hardware-clamp-gate-margin`
  passes for the per-channel analog command limits.
- `check_buck_input_power_budget.py --policy hardware-clamp-9v3` passes for the
  all-channel per-channel analog-limit input-current case.

## Remaining Release Risk

This signoff is enough to order and perform controlled first-article laser
bring-up. It does not close optical safety, measured optical output, measured
driver/sense-resistor temperature, firmware clamp behavior, duty-cycle limits,
loop transient behavior, or future laser/rail/current substitutions.

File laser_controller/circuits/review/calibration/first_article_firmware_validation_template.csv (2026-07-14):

category | target | interface_or_signal | accepted_limit | required_evidence | release_blocker
ad7606_timing | U14_CONTROL | RESET/CONVST/BUSY/CS/SCLK | SCLK <=10 MHz, sample <=100 kSPS | read-after-conversion firmware; scope capture proving RESET/CONVST/BUSY/CS/SCLK timing and BUSY fall before CS | AD7606_SYSTEM_INTERFACE
ad7606_stage_a_readback | ADC_MISO_A | DOUTA | 64 SCLK edges per sample | DOUTA one-lane readback with 64 SCLK edges raw bytes and decoded V1 V2 V3 V4 | AD7606_SYSTEM_INTERFACE
ad7606_stage_b_readback | ADC_MISO_A | DOUTA | 32 SCLK edges per sample | DOUTA dual-lane readback with 32 SCLK edges and firmware sample log | AD7606_SYSTEM_INTERFACE
ad7606_stage_b_readback | ADC_MISO_B | DOUTB | 32 SCLK edges per sample | DOUTB dual-lane readback with 32 SCLK edges and firmware sample log | AD7606_SYSTEM_INTERFACE
ad7606_scaling | RANGE_OS | +/-5 V, no oversampling | 152.59 uV/LSB | RANGE=0 and OS[2:0]=000 firmware metadata; 152.59 uV/LSB conversion | AD7606_SYSTEM_INTERFACE
ad7606_channel_order | VOUT1..4 | AD7606 V1/V2/V3/V4 | known channel ordering | known channel ordering for VOUT1 VOUT2 VOUT3 VOUT4 using channel-specific stimulus | AD7606_SYSTEM_INTERFACE
ad7606_known_input | VOUT1..4 | known voltage or TIA input | counts match expected value | known-input counts compared with expected value and recorded error limit | AD7606_SYSTEM_INTERFACE

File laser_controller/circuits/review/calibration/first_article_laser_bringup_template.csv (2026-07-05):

channel_ref | color | laser_mpn | nominal_current_limit_ma | tolerance_corner_current_ma | laser_vplus_check | fixture_required | required_measurements | release_blocker
LD1 | INFRARED | D7805I | 38.0 | 38.6 | verify 9.3 V-class LASER_V+ before enabling LD1 | wavelength-rated eyewear and enclosed beam stop | received-can pinout; one-channel-at-a-time; firmware duty/command; measured current; driver/sense-resistor temperature; external optical power; shutoff behavior | PER_DIODE_LASER_THERMAL_BUDGET
LD2 | RED | D6505I | 23.0 | 23.5 | verify 9.3 V-class LASER_V+ before enabling LD2 | wavelength-rated eyewear and enclosed beam stop | received-can pinout; one-channel-at-a-time; firmware duty/command; measured current; driver/sense-resistor temperature; external optical power; shutoff behavior | PER_DIODE_LASER_THERMAL_BUDGET
LD3 | GREEN | PLT5 520EB_P | 76.2 | 77.3 | verify 9.3 V-class LASER_V+ before enabling LD3 | wavelength-rated eyewear and enclosed beam stop | received-can pinout; one-channel-at-a-time; firmware duty/command; measured current; driver/sense-resistor temperature; external optical power; shutoff behavior | PER_DIODE_LASER_THERMAL_BUDGET
LD4 | BLUE | PLT5 450GB | 105.5 | 107.0 | verify 9.3 V-class LASER_V+ before enabling LD4 | wavelength-rated eyewear and enclosed beam stop | received-can pinout; one-channel-at-a-time; firmware duty/command; measured current; driver/sense-resistor temperature; external optical power; shutoff behavior | PER_DIODE_LASER_THERMAL_BUDGET

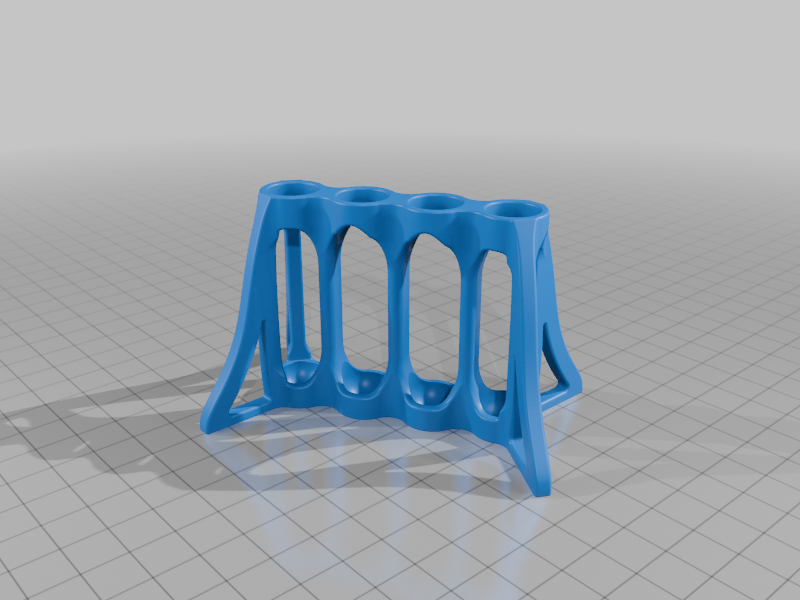
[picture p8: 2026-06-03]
models/12mm test tube base - 6674298/images/58f55dcc-f65b-452a-8cf8-ca9d7056c8bd.png

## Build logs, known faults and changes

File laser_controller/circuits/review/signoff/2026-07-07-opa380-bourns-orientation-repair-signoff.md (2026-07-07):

# OPA380 and Bourns 3224W Orientation Repair Signoff

Date: 2026-07-07 CDT

Scope: U1-U4 OPA380AID SOIC-8 TIA amplifiers and RV1-RV8 Bourns 3224W
trimmers on `circuits/laser_controller.kicad_pcb`.

## Finding

JLCPCB's assembly preview for U1, U2, U3, and U4 showed the package dot/arrow
disagreeing with the expected OPA380 pin-1 corner. Re-audit confirmed this was
a real footprint mirror defect. The old board assigned the intended schematic
nets to numeric pads, but the embedded SOIC-8 copper was mirrored relative to
TI's OPA380 top-view pinout. A numeric pad-net check alone was not enough.

The same re-audit found RV5-RV8 Bourns 3224W feedback trimmers mirrored in the
embedded PCB footprint versus the stock Bourns/KiCad physical geometry.

## Repair

`circuits/repair_orientation_sensitive_footprints.py` repairs only the confirmed
mirror-risk parts:

- U1-U4 OPA380AID SOIC-8 local footprint primitives and pads.
- RV5-RV8 Bourns 3224W feedback trimmer local footprint primitives and pads.
- Directly attached local escape traces/vias affected by those pad moves.

The repaired OPA380 local SOIC-8 pad order is:

| Pin | Local coordinate | Net |
|---:|---:|---|
| 1 | `(-2.475, -1.905)` | NC |
| 2 | `(-2.475, -0.635)` | local `PD_ANODE` summing node |
| 3 | `(-2.475, 0.635)` | local `VBIAS` |
| 4 | `(-2.475, 1.905)` | `GND` |
| 5 | `(2.475, 1.905)` | NC |
| 6 | `(2.475, 0.635)` | `VOUTx` |
| 7 | `(2.475, -0.635)` | `+5V` |
| 8 | `(2.475, -1.905)` | NC |

U1-U4 remain intentionally rotated 180 degrees on the board. With TI's SOIC-8
top-view pinout, that places physical pin 1 and the package dot at the
lower-right board corner. That is the correct board rotation, not a mirror.

The repaired Bourns 3224W local pad order is:

| Pin | Local coordinate | Net role |
|---:|---:|---|
| 1 | `(1.25, -1.45)` | end terminal |
| 2 | `(0, 1.45)` | wiper |
| 3 | `(-1.25, -1.45)` | end terminal |

RV1-RV4 use pad 2 as the VBIAS wiper. RV5-RV8 tie pad 2/wiper and pad 3 to
`VOUT1..4`, making the feedback trims rheostats with the wiper on the OPA380
output side.

## Verification

Commands run after repair:

```bash
python3 circuits/check_orientation_polarity_pcb.py --board circuits/laser_controller.kicad_pcb
kicad-cli pcb drc --all-track-errors --refill-zones --severity-all --exit-code-violations --format report --output circuits/review/generated/laser_controller_kicad9_physical_drc.rpt circuits/laser_controller.kicad_pcb
python3 circuits/check_jlcpcb_order_package.py
python3 circuits/run_laser_controller_review.py
```

Results:

- `check_orientation_polarity_pcb.py` passes U1-U4 OPA380 physical pad order,
  intentional 180-degree rotation, and pin nets against the TI OPA380 datasheet
  top-view pinout.
- `check_orientation_polarity_pcb.py` passes RV1-RV8 Bourns 3224W wiper
  geometry and nets.
- Native KiCad DRC with refilled zones reports 0 violations and 0 unconnected
  pads.
- The regenerated JLCPCB package gate passes after rebuilding Gerbers, drill
  files, BOM, CPL/POS, and transfer zip.

Visual evidence generated from the current PCB:

- `circuits/review/generated/laser_controller_top_render.png` is the full
  top-side KiCad 3D render for this board state.
- `circuits/review/generated/laser_controller_tia_top_render_crop.png` is the
  TIA-area crop showing U1-U4 with package dots at the lower-right board
  corner.
- `circuits/review/generated/opa380_orientation_visual_audit.svg` shows the TI
  OPA380 top-view pin contract next to the current U1-U4 board-side physical
  pin order and nets.
- `circuits/review/generated/opa380_orientation_visual_audit.png` is the
  rendered PNG version of the same datasheet-vs-board visual audit.

## JLCPCB Reply Basis

The old JLCPCB order package should not be approved. It was current to the
mirrored board. The regenerated package dated 2026-07-07 is the corrected
artifact. In JLCPCB's assembly preview after upload, U1-U4 should show the
SOIC package dot at the lower-right board corner for the current placement.

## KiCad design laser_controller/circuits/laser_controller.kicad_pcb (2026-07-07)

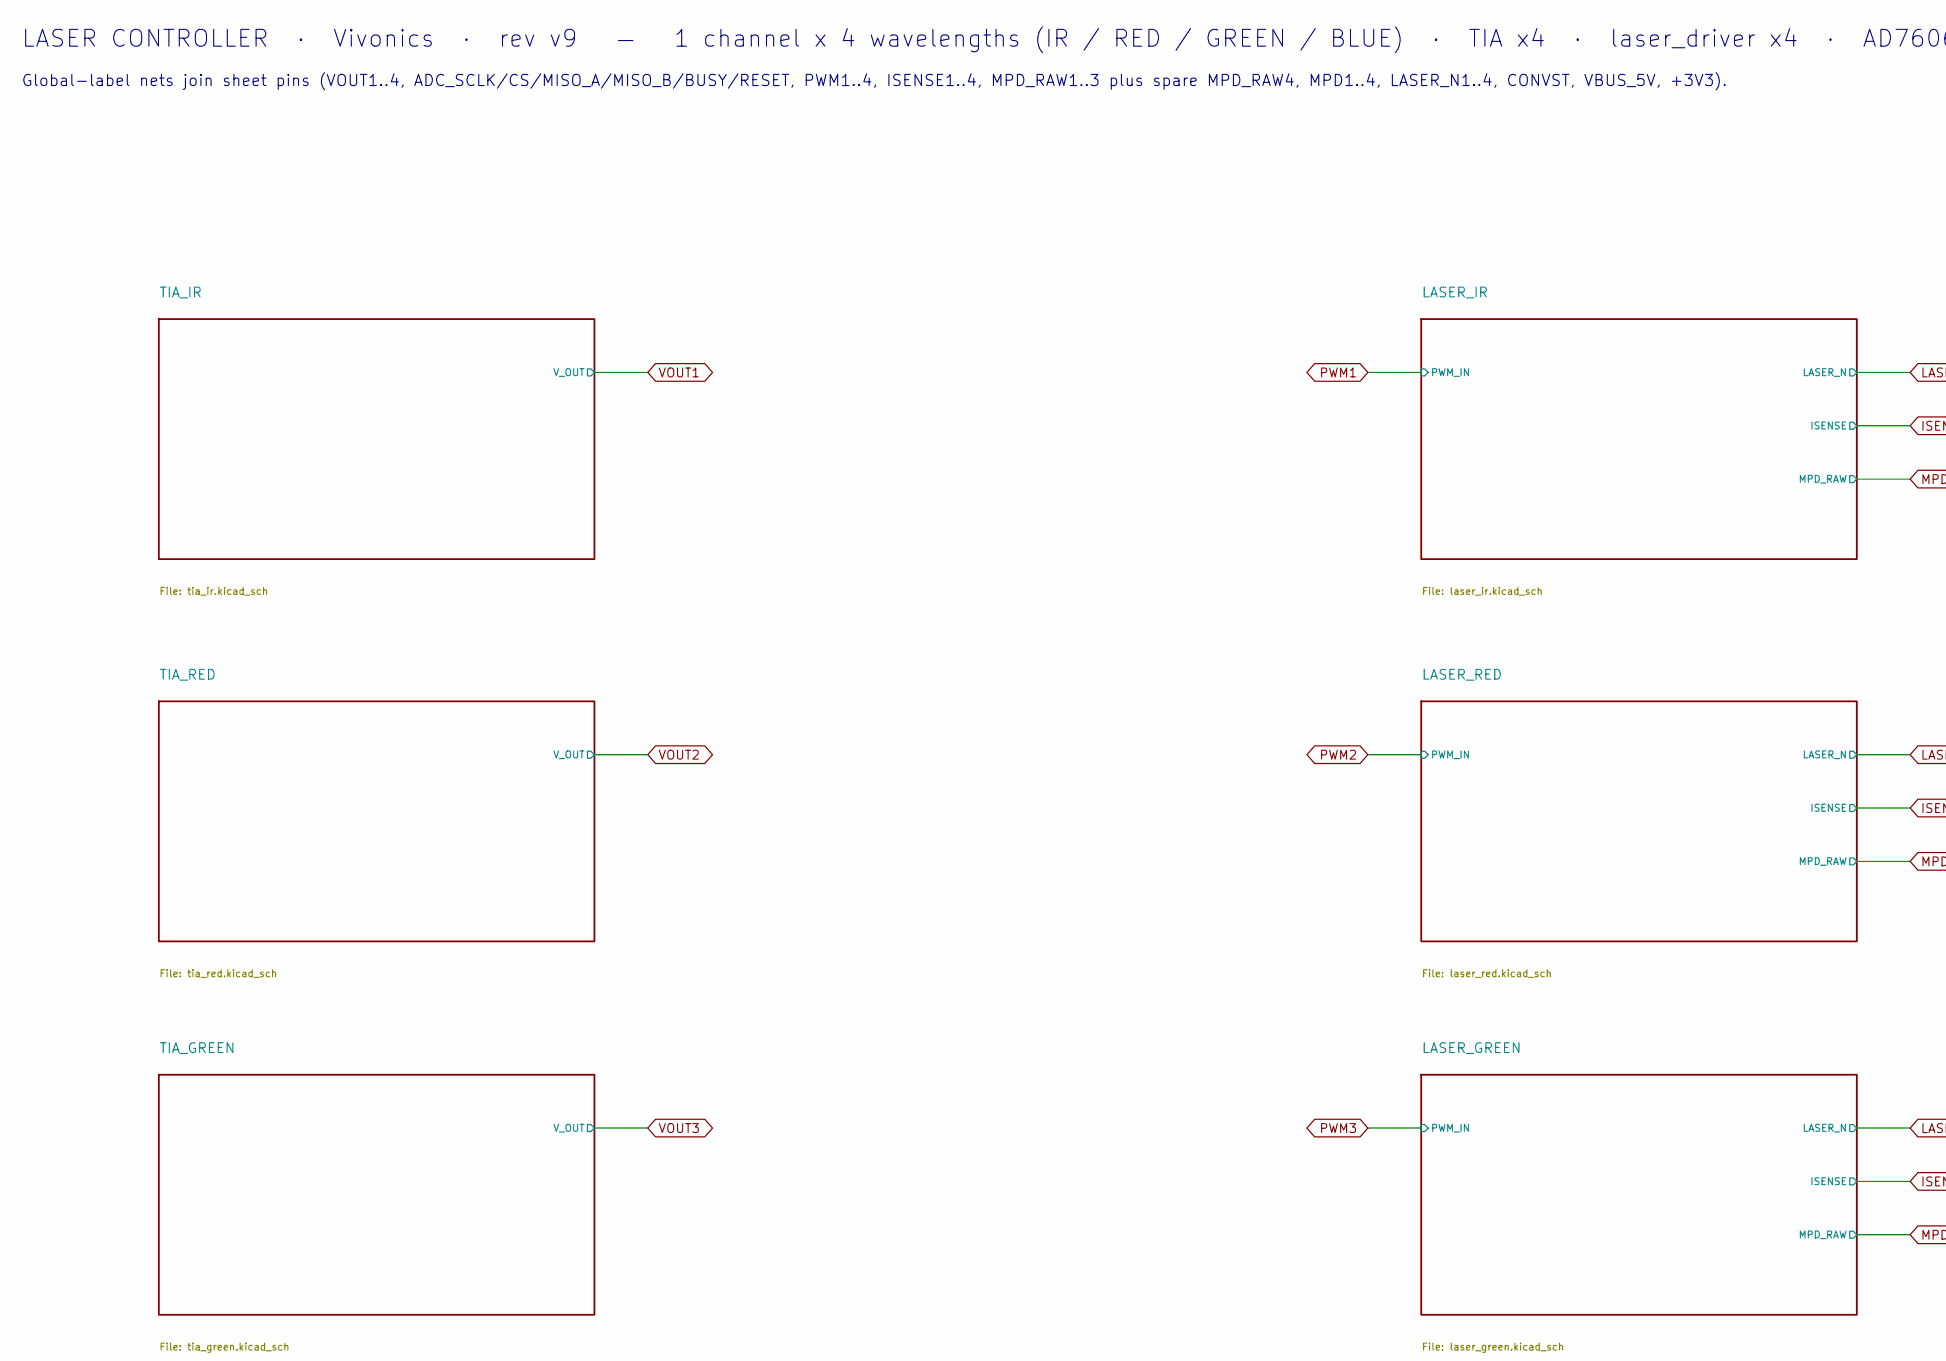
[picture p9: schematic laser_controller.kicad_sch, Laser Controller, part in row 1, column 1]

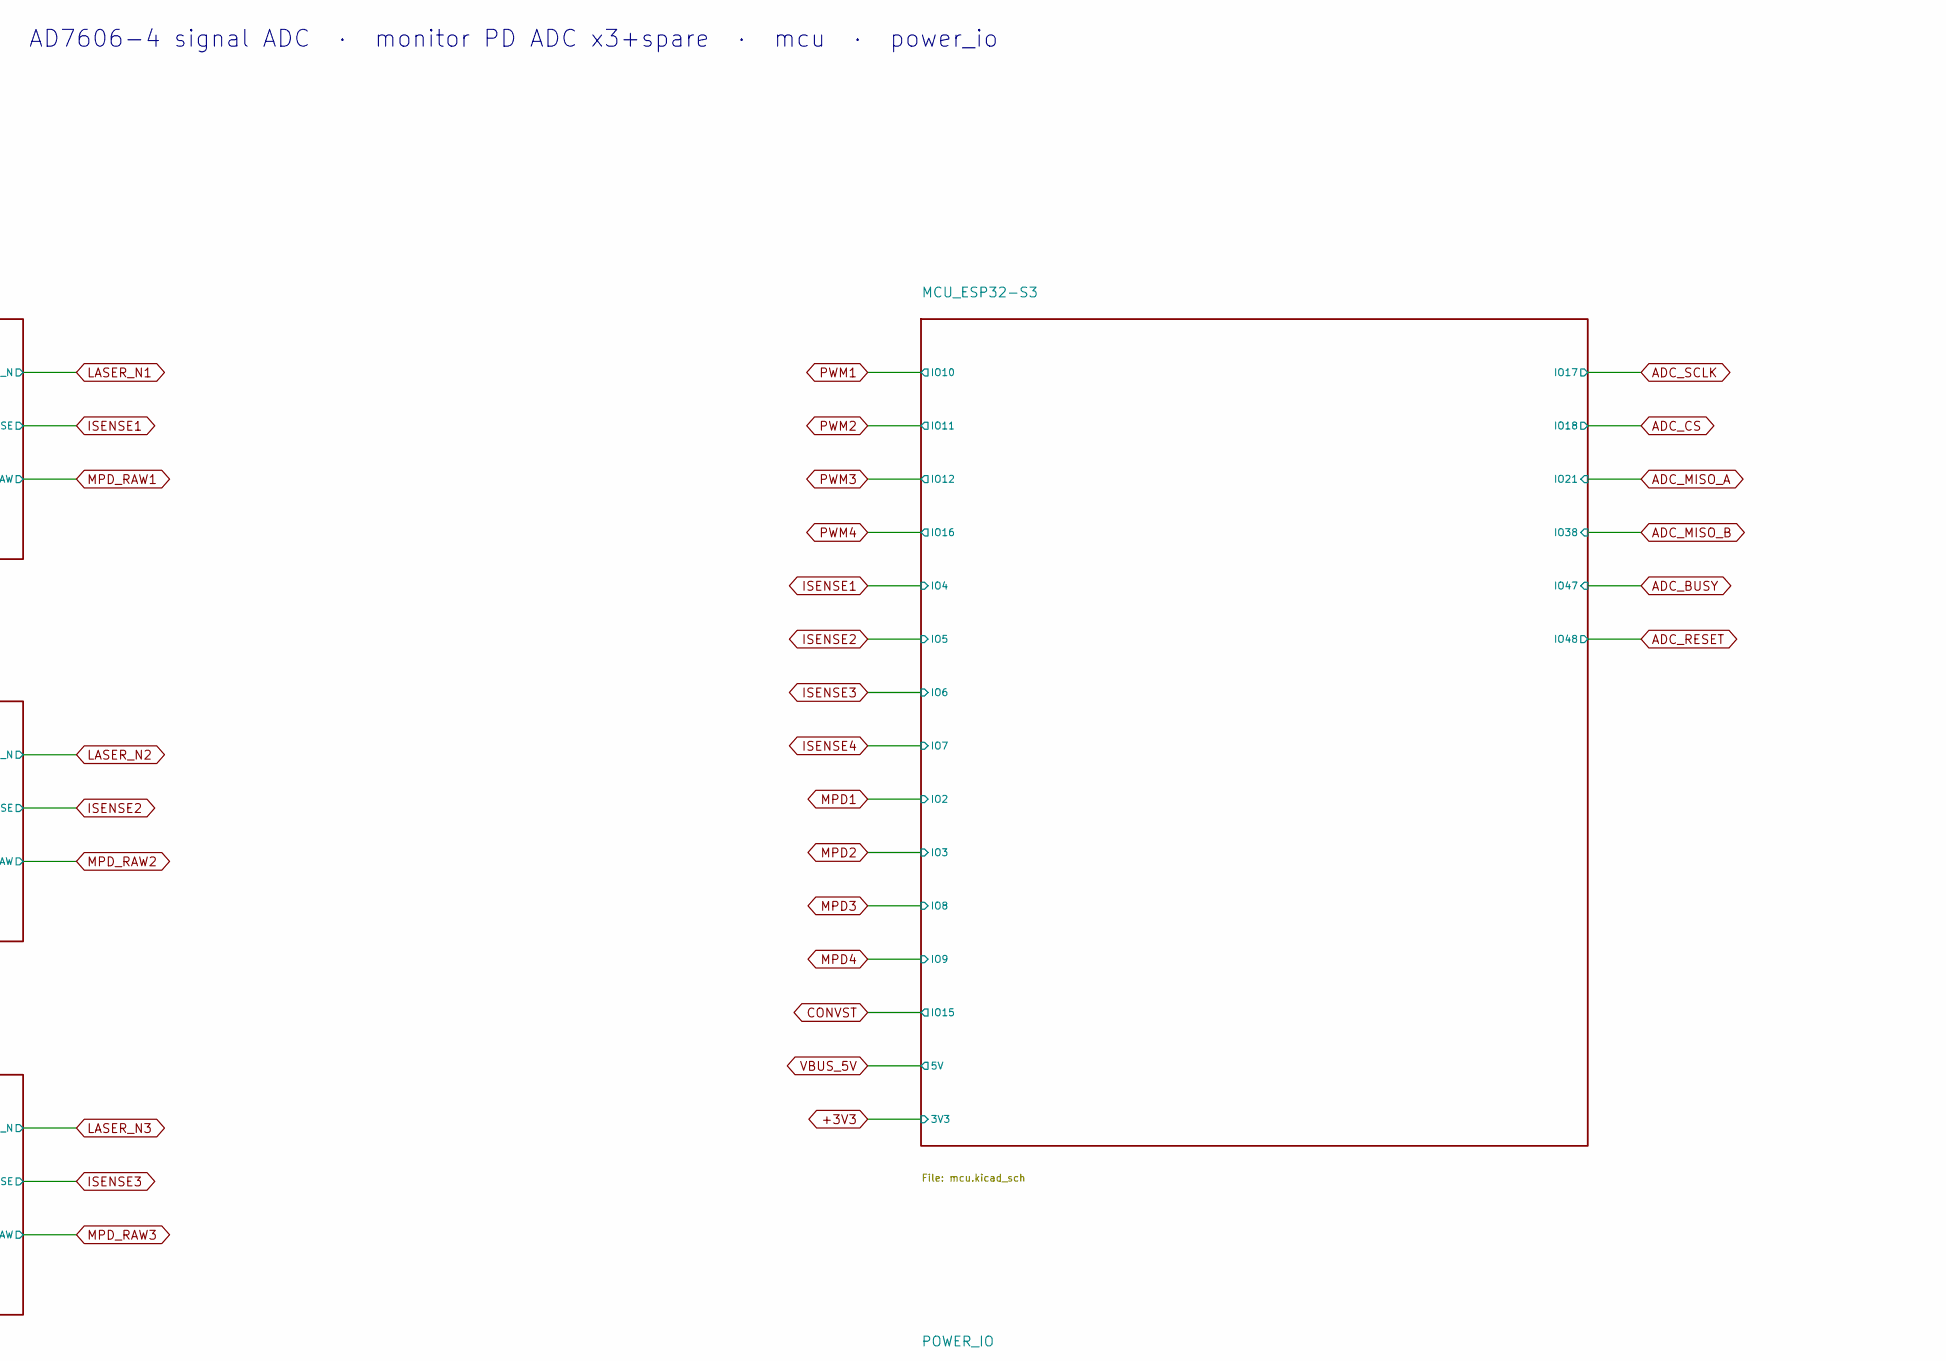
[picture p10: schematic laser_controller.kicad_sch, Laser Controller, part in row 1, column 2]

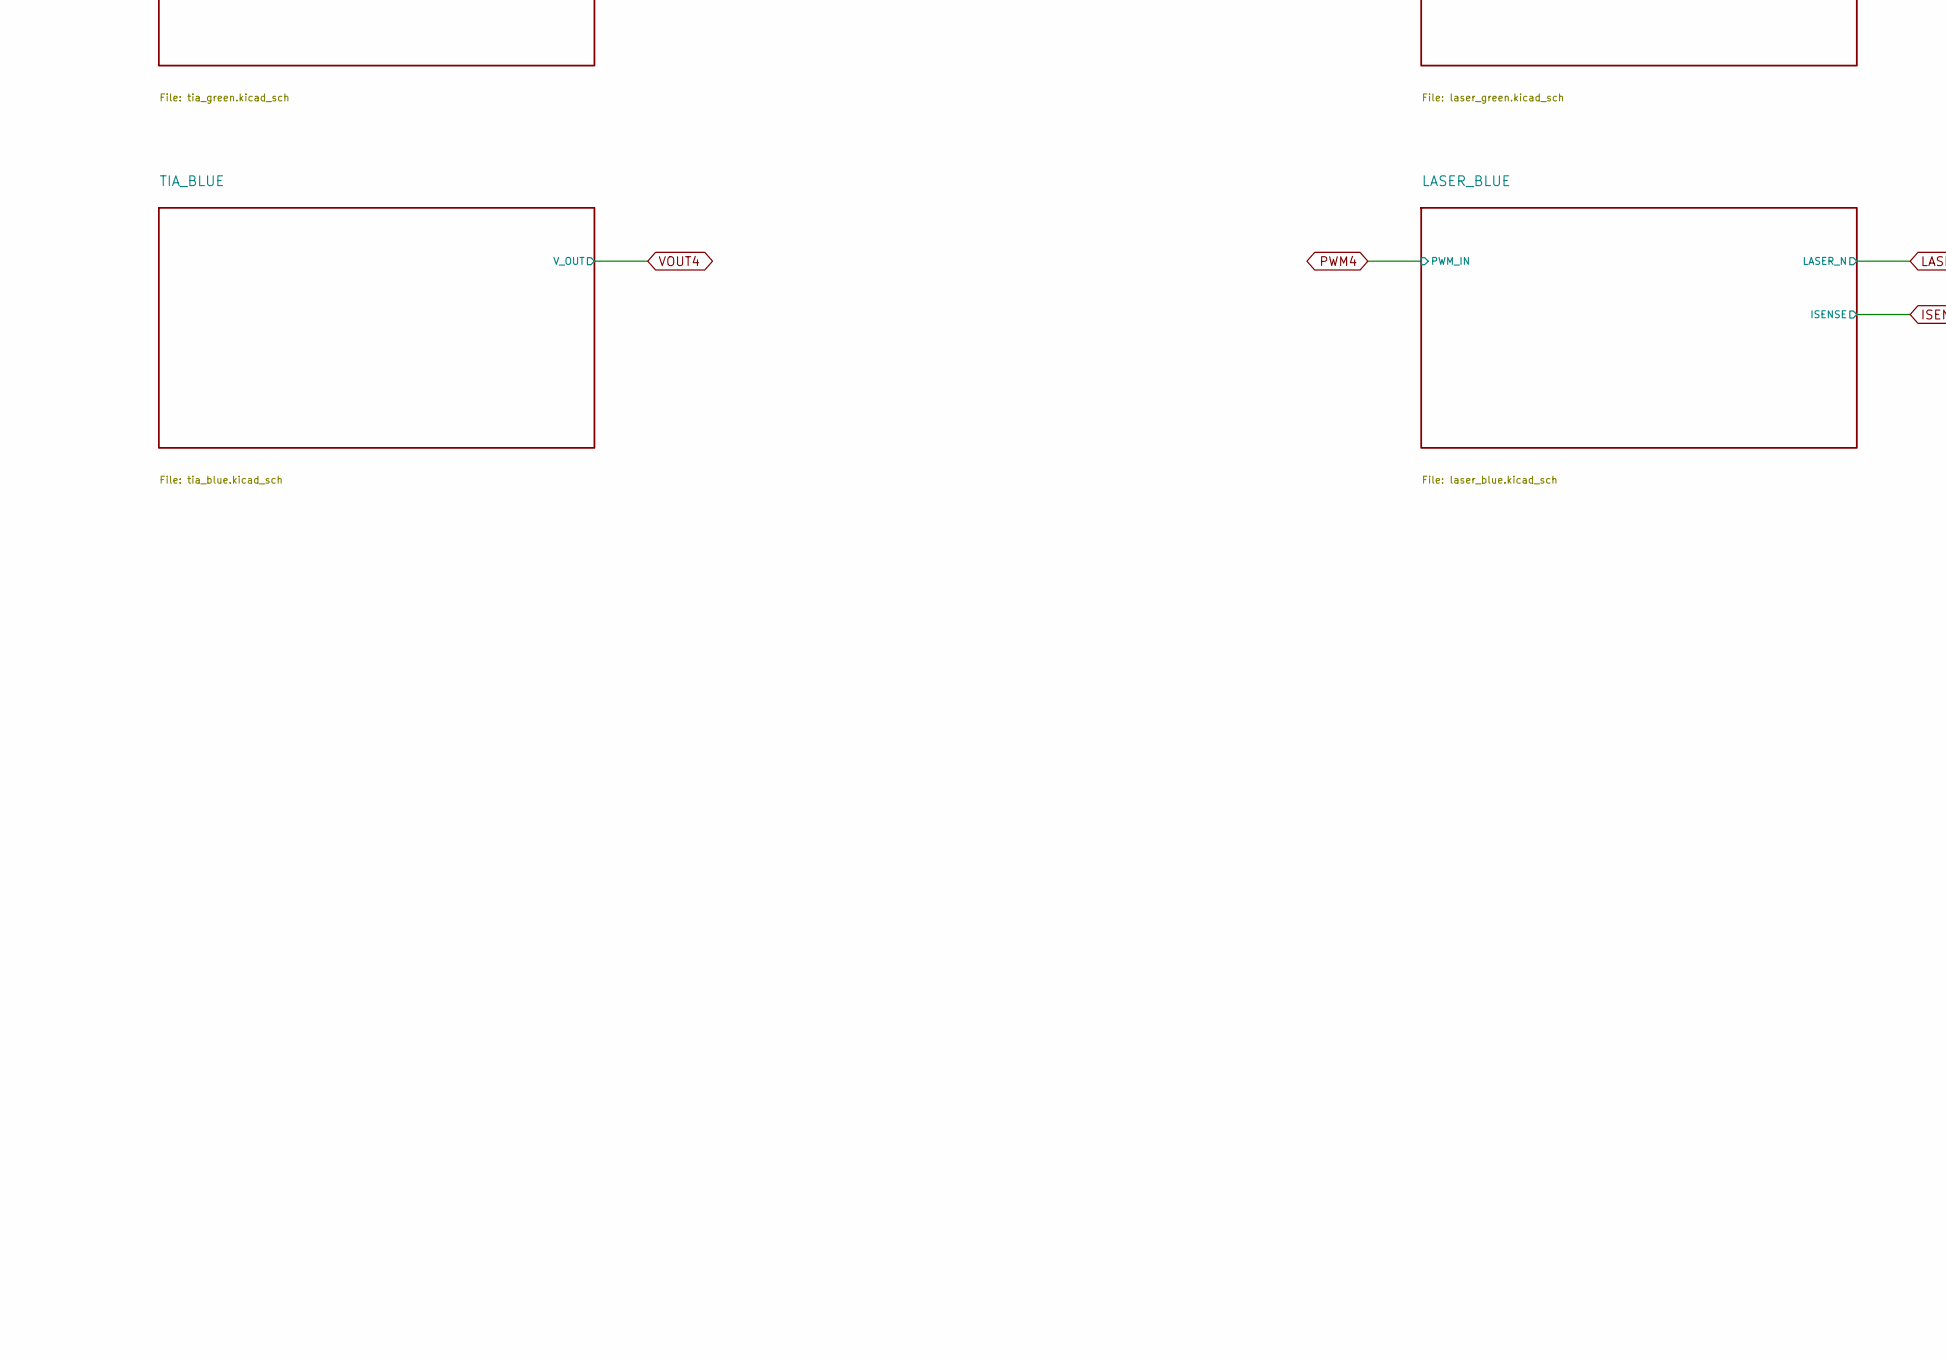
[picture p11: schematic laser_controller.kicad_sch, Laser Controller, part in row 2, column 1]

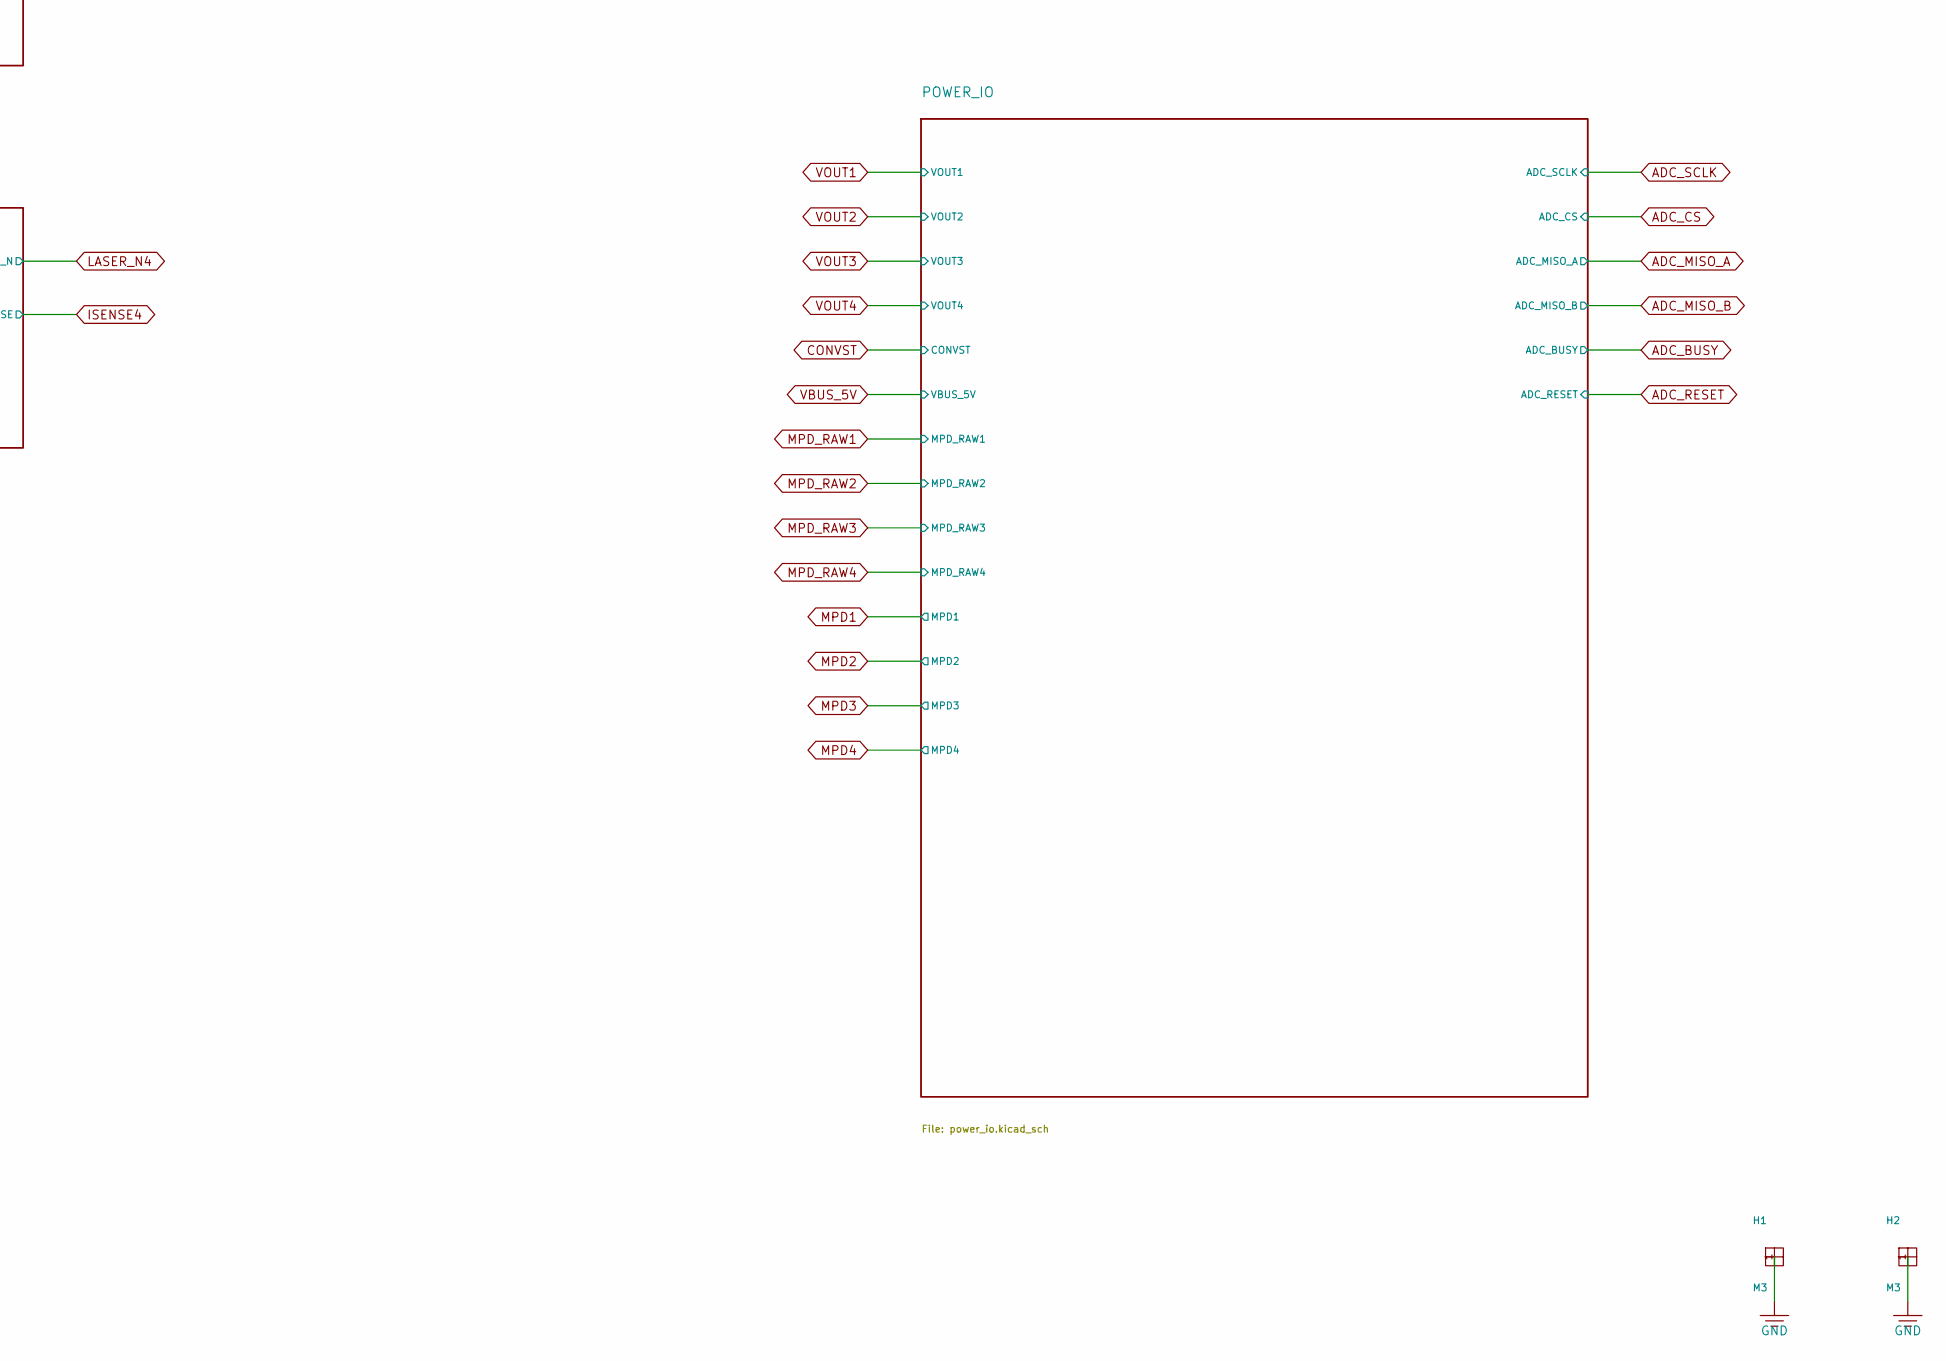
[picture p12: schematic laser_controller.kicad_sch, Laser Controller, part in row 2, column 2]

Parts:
H1, H2: M3; MountingHole_3.2mm_M3

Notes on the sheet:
LASER CONTROLLER · Vivonics · rev v9 — 1 channel x 4 wavelengths (IR / RED / GREEN / BLUE) · TIA x4 · laser_driver x4 · AD7606-4 signal ADC · monitor PD ADC x3+spare · mcu · power_io
Global-label nets join sheet pins (VOUT1..4, ADC_SCLK/CS/MISO_A/MISO_B/BUSY/RESET, PWM1..4, ISENSE1..4, MPD_RAW1..3 plus spare MPD_RAW4, MPD1..4, LASER_N1..4, CONVST, VBUS_5V, +3V3).

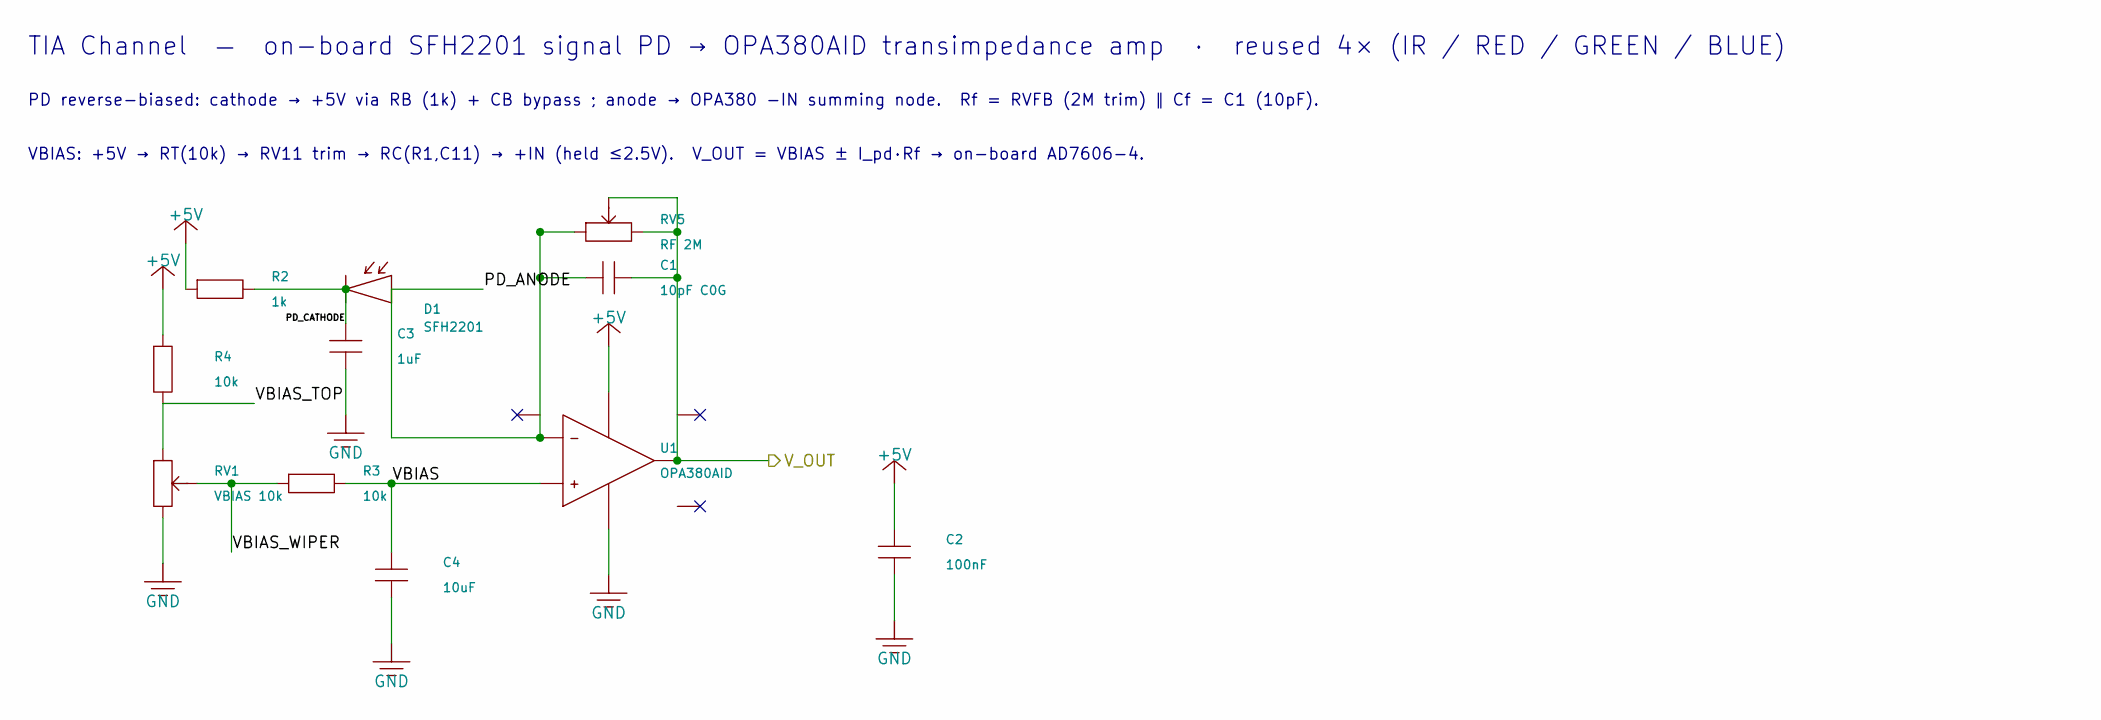
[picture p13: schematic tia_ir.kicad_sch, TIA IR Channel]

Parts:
C1: 10pF C0G; C_0603_1608Metric_Pad1.08x0.95mm_HandSolder; Part Number CC0603JRNPO9BN100; LCSC C106245
C2: 100nF; C_0402_1005Metric_Pad0.74x0.62mm_HandSolder; Part Number 0402B104K160CT; LCSC C83056
C3: 1uF; C_0402_1005Metric_Pad0.74x0.62mm_HandSolder; Part Number HGC0402R5105K250NTEJ; LCSC C7472946
C4: 10uF; C_0805_2012Metric_Pad1.18x1.45mm_HandSolder; Part Number CL21A106KAYNNNG; LCSC C318691
D1: SFH2201; Osram_SFH2201; Part Number SFH2201; LCSC C2900216
R2: 1k; R_0603_1608Metric_Pad0.98x0.95mm_HandSolder; Part Number FRC0603F1001TS; LCSC C2907002
R3, R4: 10k; R_0603_1608Metric_Pad0.98x0.95mm_HandSolder; Part Number CRCW060310K0FKEA; LCSC C844918
RV1: VBIAS 10k; Potentiometer_Bourns_3224W_Vertical; Part Number 3224W-1-103E; LCSC C81348
RV5: RF 2M; Potentiometer_Bourns_3224W_Vertical; Part Number 3224W-1-205E; LCSC C116323
U1: OPA380AID; SOIC-8_3.9x4.9mm_P1.27mm; Part Number OPA380AID; LCSC C201677

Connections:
/TIA_IR/PD_ANODE: C1.1, D1.2 (A), RV5.1, U1.2 (-)
/TIA_IR/PD_CATHODE: C3.1, D1.1 (K), R2.2
/TIA_IR/VBIAS: C4.1, R3.2, U1.3 (+)
/TIA_IR/VBIAS_TOP: R4.2, RV1.1
/TIA_IR/VBIAS_WIPER: R3.1, RV1.2 (W)
VOUT1: C1.2, RV5.2 (W), RV5.3, U1.6; also elsewhere on the board

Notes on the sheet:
TIA Channel — on-board SFH2201 signal PD → OPA380AID transimpedance amp · reused 4× (IR / RED / GREEN / BLUE)
PD reverse-biased: cathode → +5V via RB (1k) + CB bypass ; anode → OPA380 −IN summing node. Rf = RVFB (2M trim) ∥ Cf = C1 (10pF).
VBIAS: +5V → RT(10k) → RV11 trim → RC(R1,C11) → +IN (held ≤2.5V). V_OUT = VBIAS ± I_pd·Rf → on-board AD7606-4.

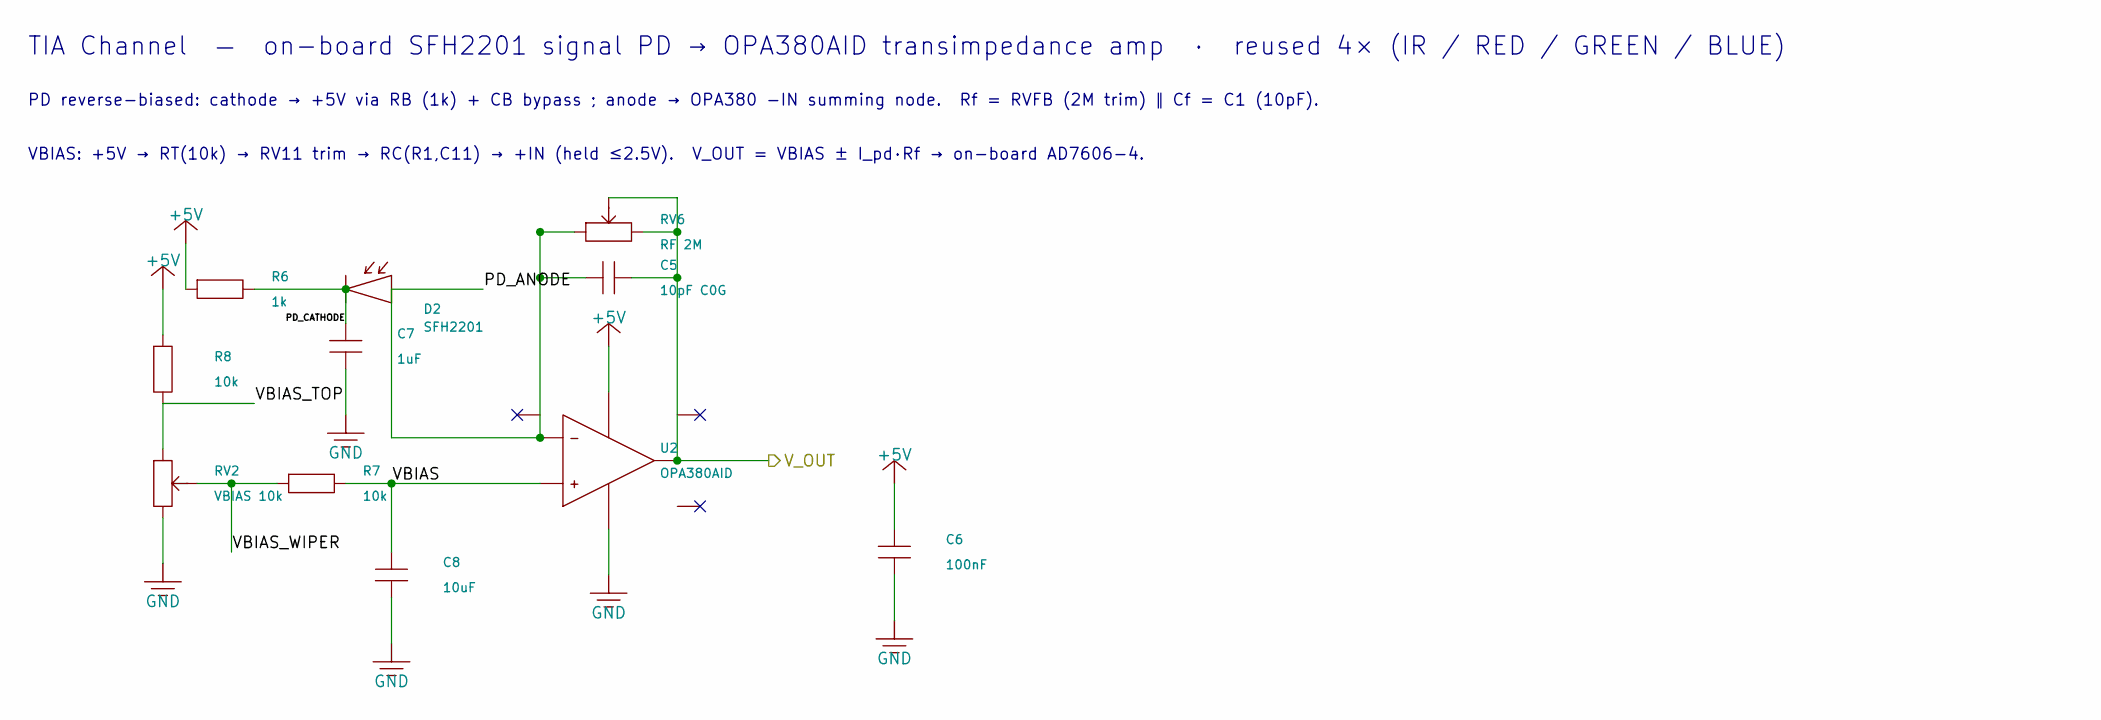
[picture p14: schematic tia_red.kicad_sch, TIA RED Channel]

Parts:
C5: 10pF C0G; C_0603_1608Metric_Pad1.08x0.95mm_HandSolder; Part Number CC0603JRNPO9BN100; LCSC C106245
C6: 100nF; C_0402_1005Metric_Pad0.74x0.62mm_HandSolder; Part Number 0402B104K160CT; LCSC C83056
C7: 1uF; C_0402_1005Metric_Pad0.74x0.62mm_HandSolder; Part Number HGC0402R5105K250NTEJ; LCSC C7472946
C8: 10uF; C_0805_2012Metric_Pad1.18x1.45mm_HandSolder; Part Number CL21A106KAYNNNG; LCSC C318691
D2: SFH2201; Osram_SFH2201; Part Number SFH2201; LCSC C2900216
R6: 1k; R_0603_1608Metric_Pad0.98x0.95mm_HandSolder; Part Number FRC0603F1001TS; LCSC C2907002
R7, R8: 10k; R_0603_1608Metric_Pad0.98x0.95mm_HandSolder; Part Number CRCW060310K0FKEA; LCSC C844918
RV2: VBIAS 10k; Potentiometer_Bourns_3224W_Vertical; Part Number 3224W-1-103E; LCSC C81348
RV6: RF 2M; Potentiometer_Bourns_3224W_Vertical; Part Number 3224W-1-205E; LCSC C116323
U2: OPA380AID; SOIC-8_3.9x4.9mm_P1.27mm; Part Number OPA380AID; LCSC C201677

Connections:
/TIA_RED/PD_ANODE: C5.1, D2.2 (A), RV6.1, U2.2 (-)
/TIA_RED/PD_CATHODE: C7.1, D2.1 (K), R6.2
/TIA_RED/VBIAS: C8.1, R7.2, U2.3 (+)
/TIA_RED/VBIAS_TOP: R8.2, RV2.1
/TIA_RED/VBIAS_WIPER: R7.1, RV2.2 (W)
VOUT2: C5.2, RV6.2 (W), RV6.3, U2.6; also elsewhere on the board

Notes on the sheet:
TIA Channel — on-board SFH2201 signal PD → OPA380AID transimpedance amp · reused 4× (IR / RED / GREEN / BLUE)
PD reverse-biased: cathode → +5V via RB (1k) + CB bypass ; anode → OPA380 −IN summing node. Rf = RVFB (2M trim) ∥ Cf = C1 (10pF).
VBIAS: +5V → RT(10k) → RV11 trim → RC(R1,C11) → +IN (held ≤2.5V). V_OUT = VBIAS ± I_pd·Rf → on-board AD7606-4.

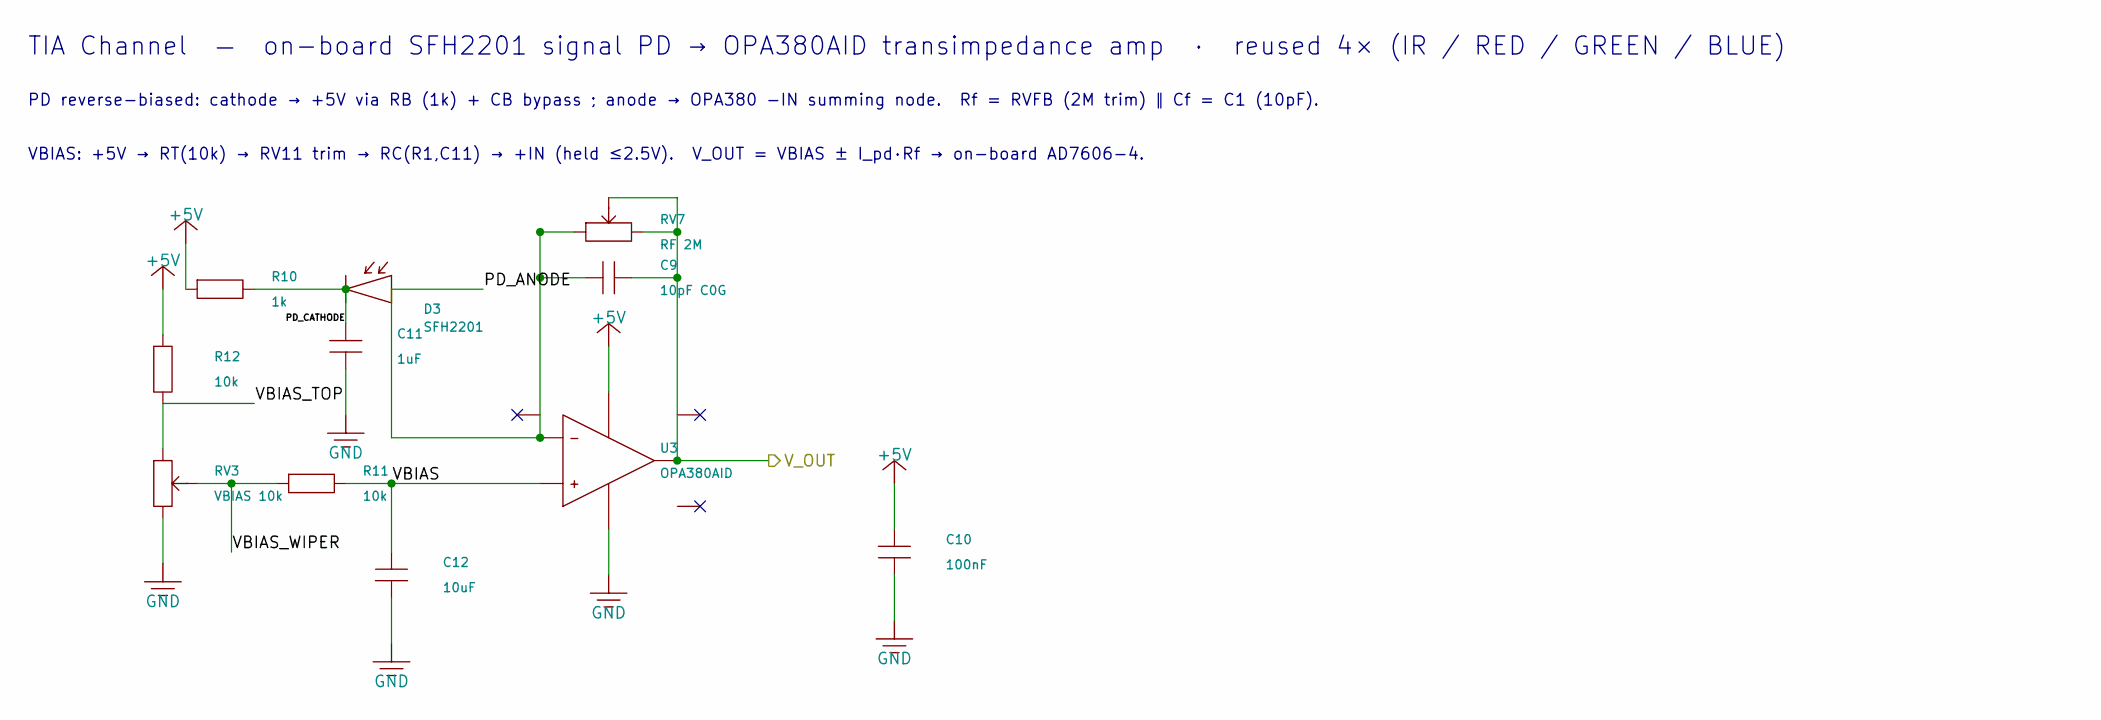
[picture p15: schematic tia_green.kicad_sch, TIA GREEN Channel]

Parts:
C9: 10pF C0G; C_0603_1608Metric_Pad1.08x0.95mm_HandSolder; Part Number CC0603JRNPO9BN100; LCSC C106245
C10: 100nF; C_0402_1005Metric_Pad0.74x0.62mm_HandSolder; Part Number 0402B104K160CT; LCSC C83056
C11: 1uF; C_0402_1005Metric_Pad0.74x0.62mm_HandSolder; Part Number HGC0402R5105K250NTEJ; LCSC C7472946
C12: 10uF; C_0805_2012Metric_Pad1.18x1.45mm_HandSolder; Part Number CL21A106KAYNNNG; LCSC C318691
D3: SFH2201; Osram_SFH2201; Part Number SFH2201; LCSC C2900216
R10: 1k; R_0603_1608Metric_Pad0.98x0.95mm_HandSolder; Part Number FRC0603F1001TS; LCSC C2907002
R11, R12: 10k; R_0603_1608Metric_Pad0.98x0.95mm_HandSolder; Part Number CRCW060310K0FKEA; LCSC C844918
RV3: VBIAS 10k; Potentiometer_Bourns_3224W_Vertical; Part Number 3224W-1-103E; LCSC C81348
RV7: RF 2M; Potentiometer_Bourns_3224W_Vertical; Part Number 3224W-1-205E; LCSC C116323
U3: OPA380AID; SOIC-8_3.9x4.9mm_P1.27mm; Part Number OPA380AID; LCSC C201677

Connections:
/TIA_GREEN/PD_ANODE: C9.1, D3.2 (A), RV7.1, U3.2 (-)
/TIA_GREEN/PD_CATHODE: C11.1, D3.1 (K), R10.2
/TIA_GREEN/VBIAS: C12.1, R11.2, U3.3 (+)
/TIA_GREEN/VBIAS_TOP: R12.2, RV3.1
/TIA_GREEN/VBIAS_WIPER: R11.1, RV3.2 (W)
VOUT3: C9.2, RV7.2 (W), RV7.3, U3.6; also elsewhere on the board

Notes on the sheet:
TIA Channel — on-board SFH2201 signal PD → OPA380AID transimpedance amp · reused 4× (IR / RED / GREEN / BLUE)
PD reverse-biased: cathode → +5V via RB (1k) + CB bypass ; anode → OPA380 −IN summing node. Rf = RVFB (2M trim) ∥ Cf = C1 (10pF).
VBIAS: +5V → RT(10k) → RV11 trim → RC(R1,C11) → +IN (held ≤2.5V). V_OUT = VBIAS ± I_pd·Rf → on-board AD7606-4.

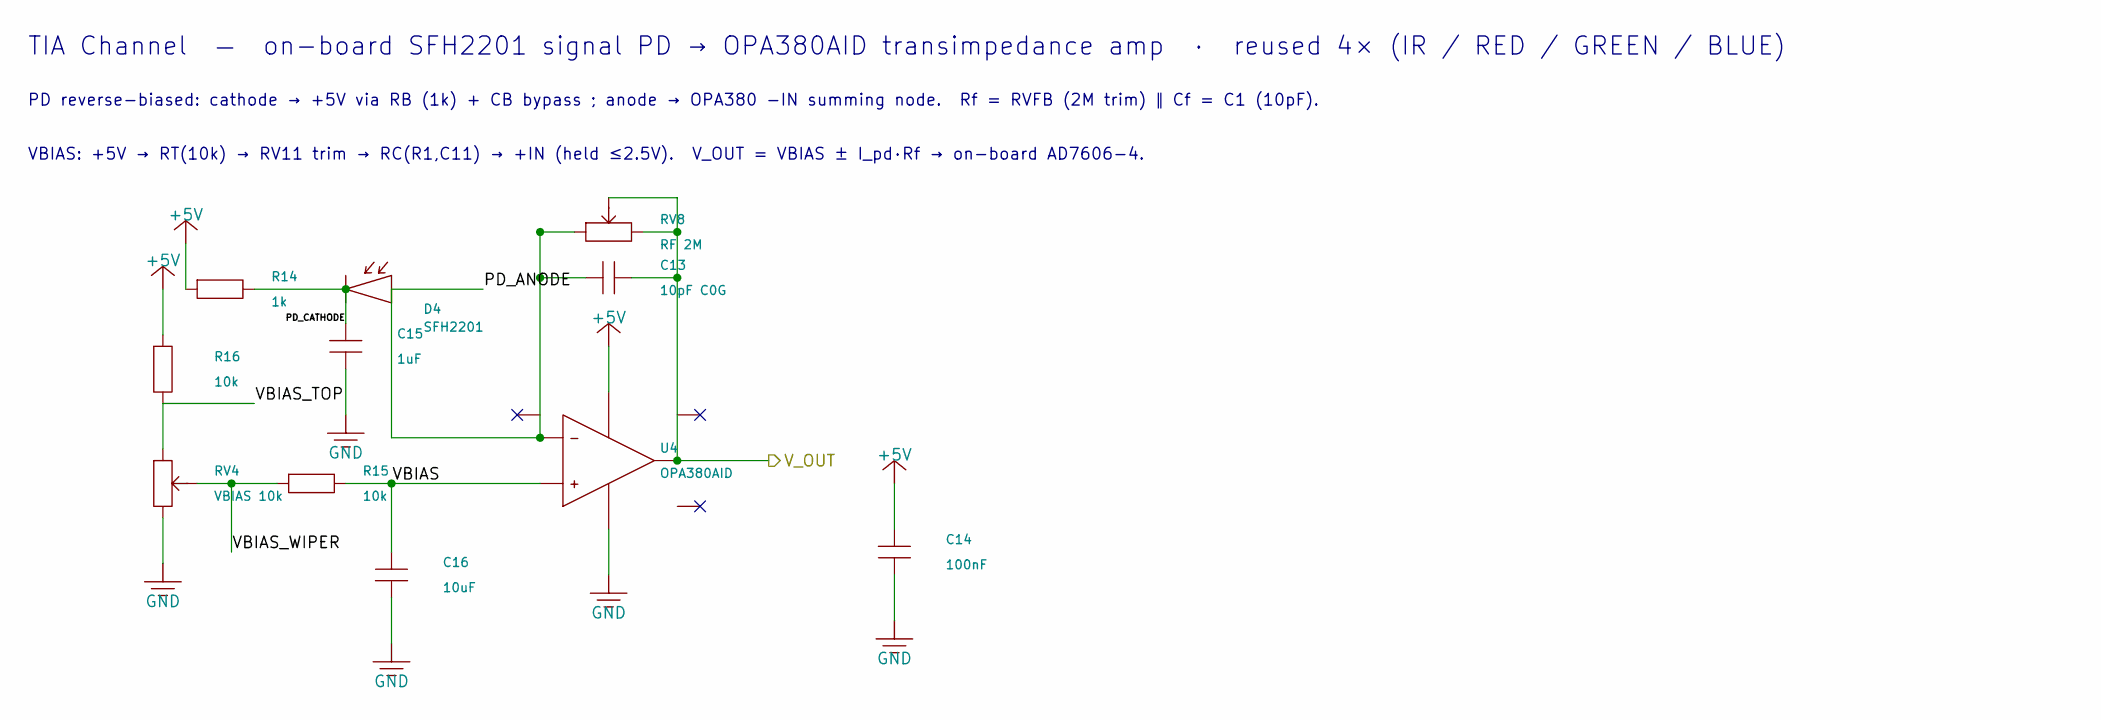
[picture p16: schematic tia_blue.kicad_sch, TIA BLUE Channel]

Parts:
C13: 10pF C0G; C_0603_1608Metric_Pad1.08x0.95mm_HandSolder; Part Number CC0603JRNPO9BN100; LCSC C106245
C14: 100nF; C_0402_1005Metric_Pad0.74x0.62mm_HandSolder; Part Number 0402B104K160CT; LCSC C83056
C15: 1uF; C_0402_1005Metric_Pad0.74x0.62mm_HandSolder; Part Number HGC0402R5105K250NTEJ; LCSC C7472946
C16: 10uF; C_0805_2012Metric_Pad1.18x1.45mm_HandSolder; Part Number CL21A106KAYNNNG; LCSC C318691
D4: SFH2201; Osram_SFH2201; Part Number SFH2201; LCSC C2900216
R14: 1k; R_0603_1608Metric_Pad0.98x0.95mm_HandSolder; Part Number FRC0603F1001TS; LCSC C2907002
R15, R16: 10k; R_0603_1608Metric_Pad0.98x0.95mm_HandSolder; Part Number CRCW060310K0FKEA; LCSC C844918
RV4: VBIAS 10k; Potentiometer_Bourns_3224W_Vertical; Part Number 3224W-1-103E; LCSC C81348
RV8: RF 2M; Potentiometer_Bourns_3224W_Vertical; Part Number 3224W-1-205E; LCSC C116323
U4: OPA380AID; SOIC-8_3.9x4.9mm_P1.27mm; Part Number OPA380AID; LCSC C201677

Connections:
/TIA_BLUE/PD_ANODE: C13.1, D4.2 (A), RV8.1, U4.2 (-)
/TIA_BLUE/PD_CATHODE: C15.1, D4.1 (K), R14.2
/TIA_BLUE/VBIAS: C16.1, R15.2, U4.3 (+)
/TIA_BLUE/VBIAS_TOP: R16.2, RV4.1
/TIA_BLUE/VBIAS_WIPER: R15.1, RV4.2 (W)
VOUT4: C13.2, RV8.2 (W), RV8.3, U4.6; also elsewhere on the board

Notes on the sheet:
TIA Channel — on-board SFH2201 signal PD → OPA380AID transimpedance amp · reused 4× (IR / RED / GREEN / BLUE)
PD reverse-biased: cathode → +5V via RB (1k) + CB bypass ; anode → OPA380 −IN summing node. Rf = RVFB (2M trim) ∥ Cf = C1 (10pF).
VBIAS: +5V → RT(10k) → RV11 trim → RC(R1,C11) → +IN (held ≤2.5V). V_OUT = VBIAS ± I_pd·Rf → on-board AD7606-4.

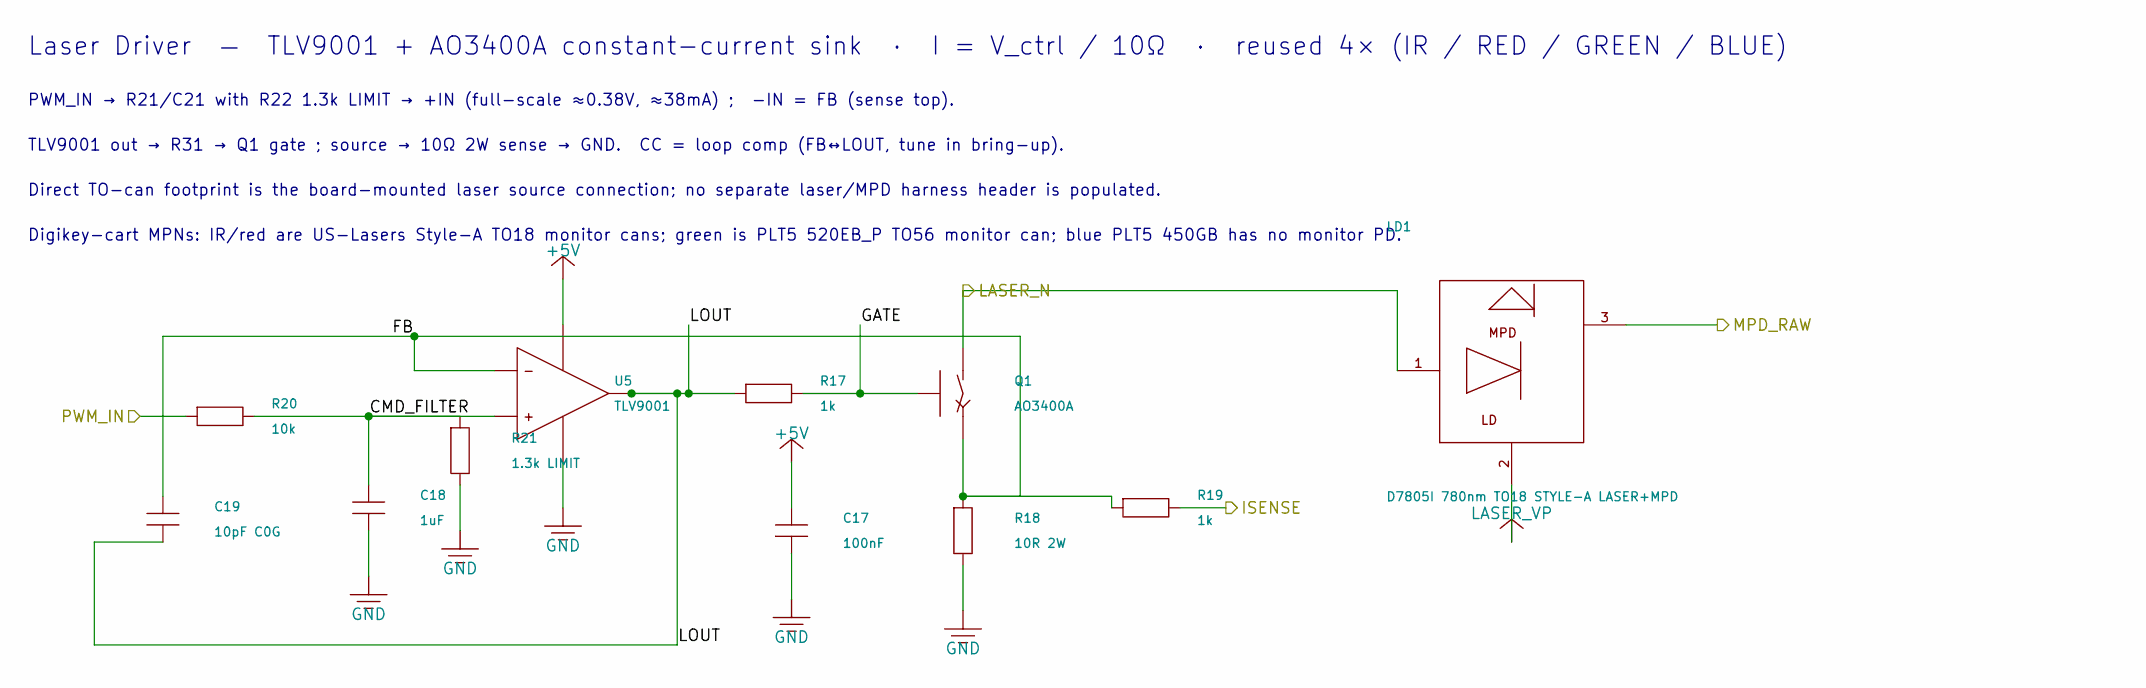
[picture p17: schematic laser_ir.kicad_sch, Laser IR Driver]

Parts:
C17: 100nF; C_0402_1005Metric_Pad0.74x0.62mm_HandSolder; Part Number 0402B104K160CT; LCSC C83056
C18: 1uF; C_0402_1005Metric_Pad0.74x0.62mm_HandSolder; Part Number HGC0402R5105K250NTEJ; LCSC C7472946
C19: 10pF C0G; C_0603_1608Metric_Pad1.08x0.95mm_HandSolder; Part Number CC0603JRNPO9BN100; LCSC C106245
LD1: D7805I 780nm TO18 STYLE-A LASER+MPD; LaserDiode_TO18-D5.6-3; Part Number D7805I
Q1: AO3400A; SOT-23; Part Number AO3400A; LCSC C20917
R17, R19: 1k; R_0603_1608Metric_Pad0.98x0.95mm_HandSolder; Part Number FRC0603F1001TS; LCSC C2907002
R18: 10R 2W; R_2512_6332Metric_Pad1.40x3.35mm_HandSolder; Part Number HoCR2512-2W-10R-1%; LCSC C5123624
R20: 10k; R_0603_1608Metric_Pad0.98x0.95mm_HandSolder; Part Number CRCW060310K0FKEA; LCSC C844918
R21: 1.3k LIMIT; R_0603_1608Metric_Pad0.98x0.95mm_HandSolder; Part Number 0603WAF1301T5E; LCSC C22767
U5: TLV9001; SOT-23-5; Part Number TLV9001IDBVR; LCSC C398363

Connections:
/LASER_IR/CMD_FILTER: C18.1, R20.2, R21.1, U5.3 (+)
/LASER_IR/FB: C19.1, Q1.2 (S), R18.1, R19.1, U5.4 (-)
/LASER_IR/GATE: Q1.1 (G), R17.2
/LASER_IR/LOUT: C19.2, R17.1, U5.1
ISENSE1: R19.2; also elsewhere on the board
LASER_N1: LD1.1 (LD_K), Q1.3 (D)
MPD_RAW1: LD1.3 (PD_A); also elsewhere on the board
PWM1: R20.1; also elsewhere on the board

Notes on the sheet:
Laser Driver — TLV9001 + AO3400A constant-current sink · I = V_ctrl / 10Ω · reused 4× (IR / RED / GREEN / BLUE)
PWM_IN → R21/C21 with R22 1.3k LIMIT → +IN (full-scale ≈0.38V, ≈38mA) ; −IN = FB (sense top).
TLV9001 out → R31 → Q1 gate ; source → 10Ω 2W sense → GND. CC = loop comp (FB↔LOUT, tune in bring-up).
Direct TO-can footprint is the board-mounted laser source connection; no separate laser/MPD harness header is populated.
Digikey-cart MPNs: IR/red are US-Lasers Style-A TO18 monitor cans; green is PLT5 520EB_P TO56 monitor can; blue PLT5 450GB has no monitor PD.

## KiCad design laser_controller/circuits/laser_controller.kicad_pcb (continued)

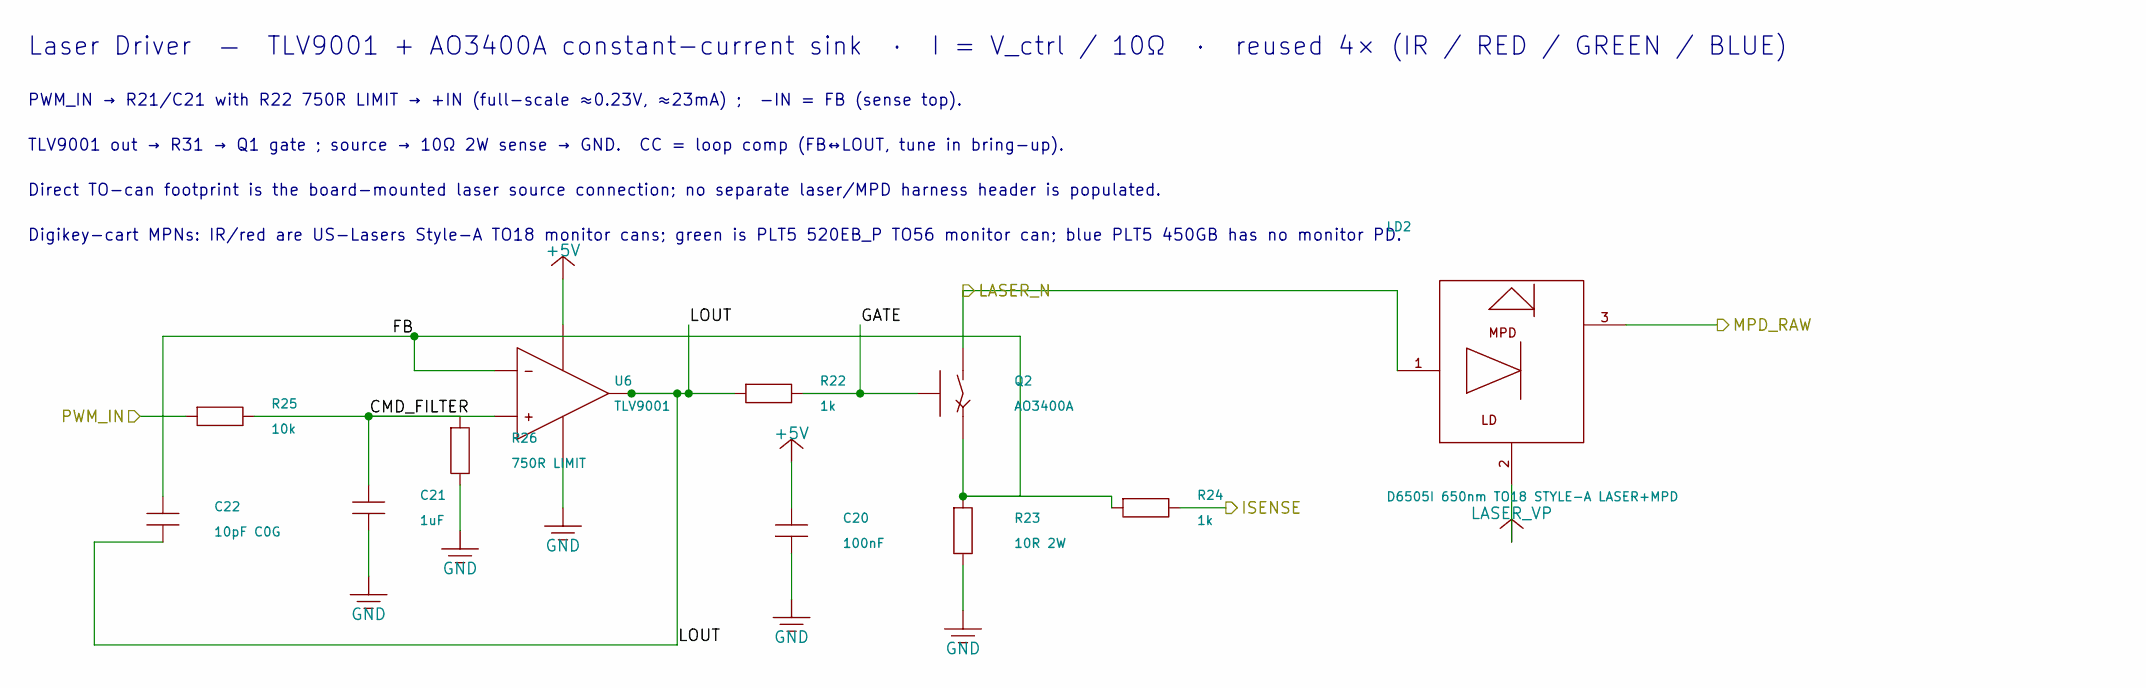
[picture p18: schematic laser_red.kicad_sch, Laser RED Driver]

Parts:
C20: 100nF; C_0402_1005Metric_Pad0.74x0.62mm_HandSolder; Part Number 0402B104K160CT; LCSC C83056
C21: 1uF; C_0402_1005Metric_Pad0.74x0.62mm_HandSolder; Part Number HGC0402R5105K250NTEJ; LCSC C7472946
C22: 10pF C0G; C_0603_1608Metric_Pad1.08x0.95mm_HandSolder; Part Number CC0603JRNPO9BN100; LCSC C106245
LD2: D6505I 650nm TO18 STYLE-A LASER+MPD; LaserDiode_TO18-D5.6-3; Part Number D6505I
Q2: AO3400A; SOT-23; Part Number AO3400A; LCSC C20917
R22, R24: 1k; R_0603_1608Metric_Pad0.98x0.95mm_HandSolder; Part Number FRC0603F1001TS; LCSC C2907002
R23: 10R 2W; R_2512_6332Metric_Pad1.40x3.35mm_HandSolder; Part Number HoCR2512-2W-10R-1%; LCSC C5123624
R25: 10k; R_0603_1608Metric_Pad0.98x0.95mm_HandSolder; Part Number CRCW060310K0FKEA; LCSC C844918
R26: 750R LIMIT; R_0603_1608Metric_Pad0.98x0.95mm_HandSolder; Part Number 0603WAF7500T5E; LCSC C23241
U6: TLV9001; SOT-23-5; Part Number TLV9001IDBVR; LCSC C398363

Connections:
/LASER_RED/CMD_FILTER: C21.1, R25.2, R26.1, U6.3 (+)
/LASER_RED/FB: C22.1, Q2.2 (S), R23.1, R24.1, U6.4 (-)
/LASER_RED/GATE: Q2.1 (G), R22.2
/LASER_RED/LOUT: C22.2, R22.1, U6.1
ISENSE2: R24.2; also elsewhere on the board
LASER_N2: LD2.1 (LD_K), Q2.3 (D)
MPD_RAW2: LD2.3 (PD_A); also elsewhere on the board
PWM2: R25.1; also elsewhere on the board

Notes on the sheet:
Laser Driver — TLV9001 + AO3400A constant-current sink · I = V_ctrl / 10Ω · reused 4× (IR / RED / GREEN / BLUE)
PWM_IN → R21/C21 with R22 750R LIMIT → +IN (full-scale ≈0.23V, ≈23mA) ; −IN = FB (sense top).
TLV9001 out → R31 → Q1 gate ; source → 10Ω 2W sense → GND. CC = loop comp (FB↔LOUT, tune in bring-up).
Direct TO-can footprint is the board-mounted laser source connection; no separate laser/MPD harness header is populated.
Digikey-cart MPNs: IR/red are US-Lasers Style-A TO18 monitor cans; green is PLT5 520EB_P TO56 monitor can; blue PLT5 450GB has no monitor PD.

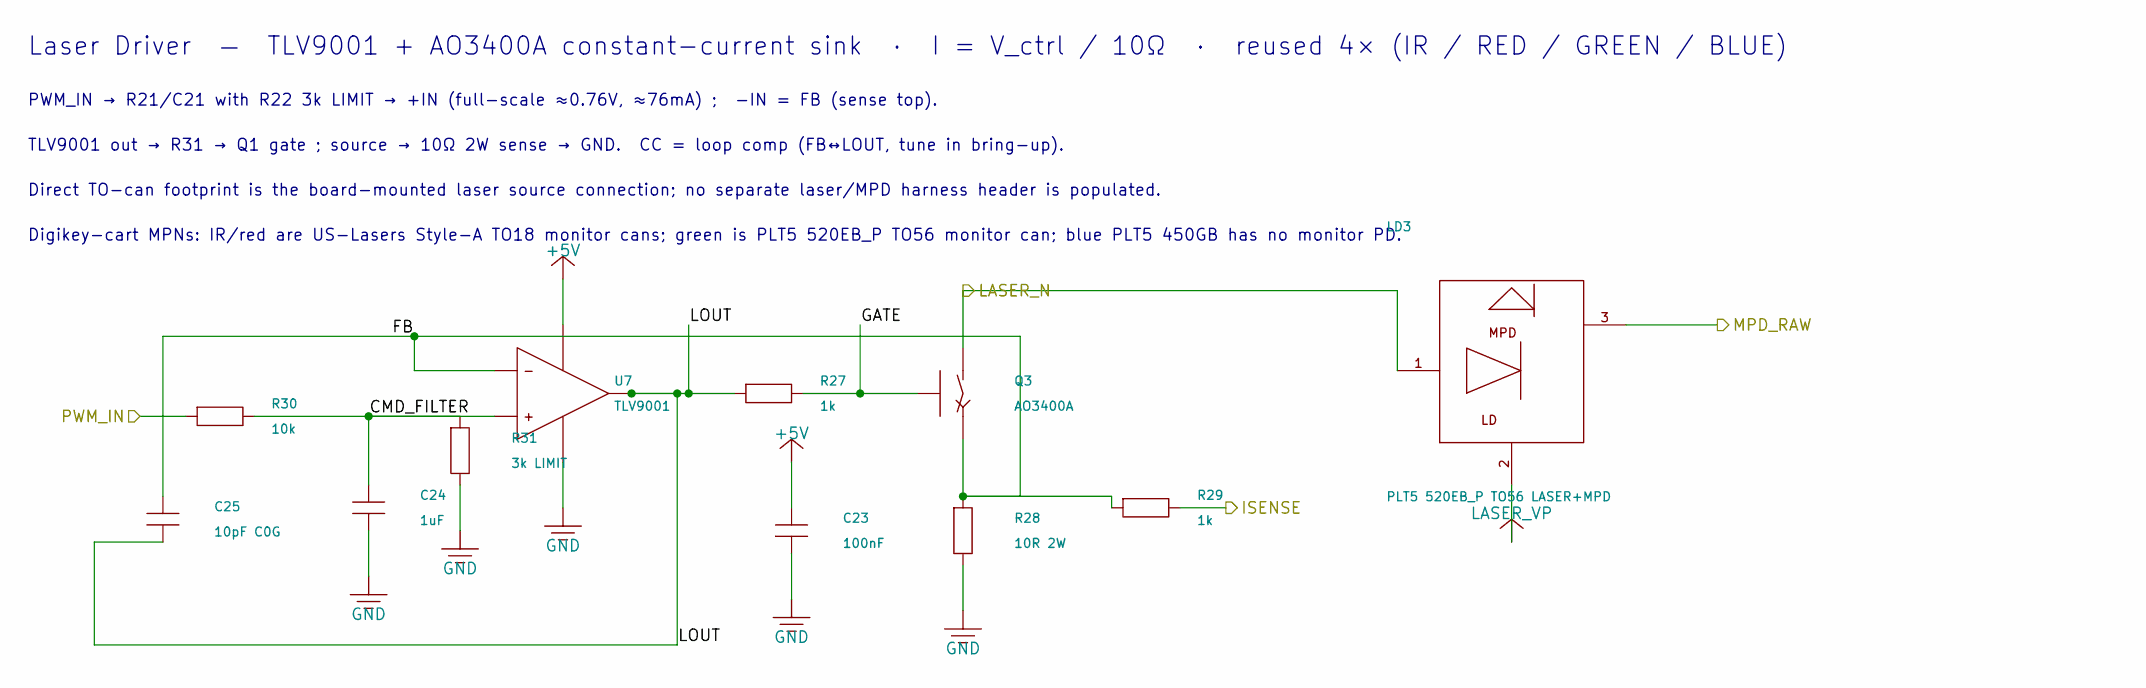
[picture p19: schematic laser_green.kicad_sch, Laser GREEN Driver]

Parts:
C23: 100nF; C_0402_1005Metric_Pad0.74x0.62mm_HandSolder; Part Number 0402B104K160CT; LCSC C83056
C24: 1uF; C_0402_1005Metric_Pad0.74x0.62mm_HandSolder; Part Number HGC0402R5105K250NTEJ; LCSC C7472946
C25: 10pF C0G; C_0603_1608Metric_Pad1.08x0.95mm_HandSolder; Part Number CC0603JRNPO9BN100; LCSC C106245
LD3: PLT5 520EB_P TO56 LASER+MPD; LaserDiode_TO56-3; Part Number PLT5 520EB_P
Q3: AO3400A; SOT-23; Part Number AO3400A; LCSC C20917
R27, R29: 1k; R_0603_1608Metric_Pad0.98x0.95mm_HandSolder; Part Number FRC0603F1001TS; LCSC C2907002
R28: 10R 2W; R_2512_6332Metric_Pad1.40x3.35mm_HandSolder; Part Number HoCR2512-2W-10R-1%; LCSC C5123624
R30: 10k; R_0603_1608Metric_Pad0.98x0.95mm_HandSolder; Part Number CRCW060310K0FKEA; LCSC C844918
R31: 3k LIMIT; R_0603_1608Metric_Pad0.98x0.95mm_HandSolder; Part Number 0603WAF3001T5E; LCSC C4211
U7: TLV9001; SOT-23-5; Part Number TLV9001IDBVR; LCSC C398363

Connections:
/LASER_GREEN/CMD_FILTER: C24.1, R30.2, R31.1, U7.3 (+)
/LASER_GREEN/FB: C25.1, Q3.2 (S), R28.1, R29.1, U7.4 (-)
/LASER_GREEN/GATE: Q3.1 (G), R27.2
/LASER_GREEN/LOUT: C25.2, R27.1, U7.1
ISENSE3: R29.2; also elsewhere on the board
LASER_N3: LD3.1 (LD_K), Q3.3 (D)
MPD_RAW3: LD3.3 (PD_A); also elsewhere on the board
PWM3: R30.1; also elsewhere on the board

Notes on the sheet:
Laser Driver — TLV9001 + AO3400A constant-current sink · I = V_ctrl / 10Ω · reused 4× (IR / RED / GREEN / BLUE)
PWM_IN → R21/C21 with R22 3k LIMIT → +IN (full-scale ≈0.76V, ≈76mA) ; −IN = FB (sense top).
TLV9001 out → R31 → Q1 gate ; source → 10Ω 2W sense → GND. CC = loop comp (FB↔LOUT, tune in bring-up).
Direct TO-can footprint is the board-mounted laser source connection; no separate laser/MPD harness header is populated.
Digikey-cart MPNs: IR/red are US-Lasers Style-A TO18 monitor cans; green is PLT5 520EB_P TO56 monitor can; blue PLT5 450GB has no monitor PD.

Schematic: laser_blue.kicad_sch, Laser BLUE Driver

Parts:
C26: 100nF; C_0402_1005Metric_Pad0.74x0.62mm_HandSolder; Part Number 0402B104K160CT; LCSC C83056
C27: 1uF; C_0402_1005Metric_Pad0.74x0.62mm_HandSolder; Part Number HGC0402R5105K250NTEJ; LCSC C7472946
C28: 10pF C0G; C_0603_1608Metric_Pad1.08x0.95mm_HandSolder; Part Number CC0603JRNPO9BN100; LCSC C106245
LD4: PLT5 450GB TO56 LASER CASE; LaserDiode_TO56-3; Part Number PLT5 450GB
Q4: AO3400A; SOT-23; Part Number AO3400A; LCSC C20917
R32, R34: 1k; R_0603_1608Metric_Pad0.98x0.95mm_HandSolder; Part Number FRC0603F1001TS; LCSC C2907002
R33: 10R 2W; R_2512_6332Metric_Pad1.40x3.35mm_HandSolder; Part Number HoCR2512-2W-10R-1%; LCSC C5123624
R35: 10k; R_0603_1608Metric_Pad0.98x0.95mm_HandSolder; Part Number CRCW060310K0FKEA; LCSC C844918
R36: 4.7k LIMIT; R_0603_1608Metric_Pad0.98x0.95mm_HandSolder; Part Number 0603WAF4701T5E; LCSC C23162
U8: TLV9001; SOT-23-5; Part Number TLV9001IDBVR; LCSC C398363

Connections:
/LASER_BLUE/CMD_FILTER: C27.1, R35.2, R36.1, U8.3 (+)
/LASER_BLUE/FB: C28.1, Q4.2 (S), R33.1, R34.1, U8.4 (-)
/LASER_BLUE/GATE: Q4.1 (G), R32.2
/LASER_BLUE/LOUT: C28.2, R32.1, U8.1
ISENSE4: R34.2; also elsewhere on the board
LASER_N4: LD4.3 (LD_K), Q4.3 (D)
PWM4: R35.1; also elsewhere on the board

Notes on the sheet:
Laser Driver — TLV9001 + AO3400A constant-current sink · I = V_ctrl / 10Ω · reused 4× (IR / RED / GREEN / BLUE)
PWM_IN → R21/C21 with R22 4.7k LIMIT → +IN (full-scale ≈1.06V, ≈106mA) ; −IN = FB (sense top).
TLV9001 out → R31 → Q1 gate ; source → 10Ω 2W sense → GND. CC = loop comp (FB↔LOUT, tune in bring-up).
Direct TO-can footprint is the board-mounted laser source connection; no separate laser/MPD harness header is populated.
Digikey-cart MPNs: IR/red are US-Lasers Style-A TO18 monitor cans; green is PLT5 520EB_P TO56 monitor can; blue PLT5 450GB has no monitor PD.

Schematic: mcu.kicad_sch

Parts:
C41, C42, C47: C_10uF; C_0805_2012Metric_Pad1.18x1.45mm_HandSolder; Part Number CL21A106KAYNNNG; LCSC C318691
C43: 100nF; C_0402_1005Metric_Pad0.74x0.62mm_HandSolder; Part Number 0402B104K160CT; LCSC C83056
C44, C45, C46: 1uF; C_0402_1005Metric_Pad0.74x0.62mm_HandSolder; Part Number HGC0402R5105K250NTEJ; LCSC C7472946
D7, D8, D9, D11, D12, D14: ESD_5V; D_SOD-523; Part Number LESD5D5.0CT1G(UMW); LCSC C5199850
D10, D13: D_1N5819HW; D_SOD-123; Part Number 1N5819HW-7-F; LCSC C82544
J1, J2: USB_MINI_B; USB_Mini-B_Wuerth_65100516121_Horizontal; Part Number 920-462A2021S10101; LCSC C46391
J7: C192300; PinHeader_2x04_P2.54mm_SMD_Vertical_C192300; Part Number 2.54-2*4P; LCSC C192300
Q5: Q_L8050QLT1G; SOT-23; Part Number L8050QLT1G; LCSC C49581
Q6: Q_L8550HQLT1G; SOT-23; Part Number L8550HQLT1G; LCSC C39282
R50, R51, R52, R53, R54, R58, R59, R60: 10K; R_0402_1005Metric_Pad0.72x0.64mm_HandSolder; Part Number ERJ2RKF1002X; LCSC C191123
R55: 22.1K; R_0402_1005Metric_Pad0.72x0.64mm_HandSolder; Part Number FRC0402F2212TS; LCSC C2929993
R56: 47.5K; R_0603_1608Metric_Pad0.98x0.95mm_HandSolder; Part Number 0603WAF4752T5E; LCSC C23061
R57: 1K; R_0402_1005Metric_Pad0.72x0.64mm_HandSolder; Part Number RT0402BRD071KL; LCSC C852624
SW1, SW2, SW3: SW_PUSH; SW_SPST_PTS645; Part Number K2-1102SP-C4SC-04; LCSC C127509
U9: ESP32-S3-WROOM-1; Part Number ESP32-S3-WROOM-1-N16; LCSC C2913199
U10: CP2102N-Axx-xQFN28; QFN-28-1EP_5x5mm_P0.5mm_EP3.35x3.35mm; Part Number CP2102N-A02-GQFN28R; LCSC C964632

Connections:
+3V3: C43.1, C47.1, J7.3 (+3V3), J7.4 (+3V3), R52.1, R53.1, R54.1, R57.1, R59.1, R60.2, U9.2 (3V3), U10.6 (VDD), U10.7 (VREGIN); also elsewhere on the board
/MCU_ESP32-S3/AUTO_BOOT_BASE: Q6.1 (B), R51.2
/MCU_ESP32-S3/AUTO_EN_BASE: Q5.1 (B), R50.2
/MCU_ESP32-S3/CP2102_RST: R57.2, U10.9 (~RST)
/MCU_ESP32-S3/CP2102_SUSPEND_N: R58.1, U10.11 (~SUSPEND)
/MCU_ESP32-S3/CP2102_VBUS: C45.1, R55.1, R56.2, U10.8 (VBUS)
/MCU_ESP32-S3/D+: D8.2 (A2), J1.3 (D+), U10.4 (D+)
/MCU_ESP32-S3/D-: D7.2 (A2), J1.2 (D-), U10.5 (D-)
/MCU_ESP32-S3/DTR: Q6.3 (C), R50.1, U10.28 (~DTR)
/MCU_ESP32-S3/EN: C44.1, Q5.3 (C), R54.2, SW1.1, U9.3 (EN)
/MCU_ESP32-S3/FACT: R52.2, SW3.1, U9.39 (GPIO1/TOUCH1/ADC1_CH0)
/MCU_ESP32-S3/IO13: R60.1, U9.21 (GPIO13/TOUCH13/ADC2_CH2/FSPIQ/FSPIIO7/S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)
/MCU_ESP32-S3/IO14: R59.2, U9.22 (GPIO14/TOUCH14/ADC2_CH3/FSPIWP/FSPIDQS/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)
/MCU_ESP32-S3/IO19: D12.2 (A2), J2.2 (D-), U9.13 (GPIO19/U1RTS/ADC2_CH8/CLK_OUT2/USB_D-)
/MCU_ESP32-S3/IO20: D11.2 (A2), J2.3 (D+), U9.14 (GPIO20/U1CTS/ADC2_CH9/CLK_OUT1/USB_D+)
/MCU_ESP32-S3/IO43: U9.37 (U0TXD/GPIO43/CLK_OUT1), U10.25 (RXD)
/MCU_ESP32-S3/IO44: U9.36 (U0RXD/GPIO44/CLK_OUT2), U10.26 (TXD)
/MCU_ESP32-S3/PROG: C46.1, Q6.2 (E), R53.2, SW2.1, U9.27 (GPIO0/BOOT)
/MCU_ESP32-S3/RTS: Q5.2 (E), R51.1, U10.24 (~RTS)
/MCU_ESP32-S3/USB_NATIVE_CONN_VBUS: D13.2 (A), J2.1 (VBUS)
/MCU_ESP32-S3/USB_UART_CONN_VBUS: D10.2 (A), J1.1 (VBUS)
ADC_BUSY: U9.24 (GPIO47/SPICLK_P/SUBSPICLK_P_DIFF); also elsewhere on the board
ADC_CS: U9.11 (GPIO18/U1RXD/ADC2_CH7/CLK_OUT3); also elsewhere on the board
ADC_MISO_A: U9.23 (GPIO21); also elsewhere on the board
ADC_MISO_B: U9.31 (GPIO38/FSPIWP/SUBSPIWP); also elsewhere on the board
ADC_RESET: U9.25 (GPIO48/SPICLK_N/SUBSPICLK_N_DIFF); also elsewhere on the board
ADC_SCLK: U9.10 (GPIO17/U1TXD/ADC2_CH6); also elsewhere on the board
CONVST: U9.8 (GPIO15/U0RTS/ADC2_CH4/XTAL_32K_P); also elsewhere on the board
ISENSE1: U9.4 (GPIO4/TOUCH4/ADC1_CH3); also elsewhere on the board
ISENSE2: U9.5 (GPIO5/TOUCH5/ADC1_CH4); also elsewhere on the board
ISENSE3: U9.6 (GPIO6/TOUCH6/ADC1_CH5); also elsewhere on the board
ISENSE4: U9.7 (GPIO7/TOUCH7/ADC1_CH6); also elsewhere on the board
MPD1: U9.38 (GPIO2/TOUCH2/ADC1_CH1); also elsewhere on the board
MPD2: U9.15 (GPIO3/TOUCH3/ADC1_CH2); also elsewhere on the board
MPD3: U9.12 (GPIO8/TOUCH8/ADC1_CH7/SUBSPICS1); also elsewhere on the board
MPD4: U9.17 (GPIO9/TOUCH9/ADC1_CH8/FSPIHD/SUBSPIHD); also elsewhere on the board
PWM1: U9.18 (GPIO10/TOUCH10/ADC1_CH9/FSPICS0/FSPIIO4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); also elsewhere on the board
PWM2: U9.19 (GPIO11/TOUCH11/ADC2_CH0/FSPID/FSPIIO5/S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); also elsewhere on the board
PWM3: U9.20 (GPIO12/TOUCH12/ADC2_CH1/FSPICLK/FSPIIO6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); also elsewhere on the board
PWM4: U9.9 (GPIO16/U0CTS/ADC2_CH5/XTAL_32K_N); also elsewhere on the board

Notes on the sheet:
J7 4x2 SMT power header (C192300): 1/2 GND, 3/4 +3V3, 5/6 +5V, 7/8 VIN_24V.

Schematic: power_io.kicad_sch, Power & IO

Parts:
C34: 10uF +5V bulk; C_0805_2012Metric_Pad1.18x1.45mm_HandSolder; Part Number CL21A106KAYNNNG; LCSC C318691
C35, C49: 100nF; C_0402_1005Metric_Pad0.74x0.62mm_HandSolder; Part Number 0402B104K160CT; LCSC C83056
C36: 100nF MPD bias; C_0402_1005Metric_Pad0.74x0.62mm_HandSolder; Part Number 0402B104K160CT; LCSC C83056
C37, C38, C39, C40: 100nF MPD ADC; C_0402_1005Metric_Pad0.74x0.62mm_HandSolder; Part Number 0402B104K160CT; LCSC C83056
C48: 1uF; C_0402_1005Metric_Pad0.74x0.62mm_HandSolder; Part Number HGC0402R5105K250NTEJ; LCSC C7472946
C50: 10uF; C_0805_2012Metric_Pad1.18x1.45mm_HandSolder; Part Number CL21A106KAYNNNG; LCSC C318691
C51, C52, C53, C54: 100nF ADC AVCC; C_0402_1005Metric_Pad0.74x0.62mm_HandSolder; Part Number 0402B104K160CT; LCSC C83056
C55: 100nF ADC VDRIVE; C_0402_1005Metric_Pad0.74x0.62mm_HandSolder; Part Number 0402B104K160CT; LCSC C83056
C56: 10uF ADC AVCC; C_0805_2012Metric_Pad1.18x1.45mm_HandSolder; Part Number CL21A106KAYNNNG; LCSC C318691
C57, C58: 1uF ADC REGCAP; C_0402_1005Metric_Pad0.74x0.62mm_HandSolder; Part Number HGC0402R5105K250NTEJ; LCSC C7472946
C59: 10uF ADC REF; C_0805_2012Metric_Pad1.18x1.45mm_HandSolder; Part Number CL21A106KAYNNNG; LCSC C318691
C60: 10uF ADC REFCAP; C_0805_2012Metric_Pad1.18x1.45mm_HandSolder; Part Number CL21A106KAYNNNG; LCSC C318691
C61, C62: 10uF 50V; C_1206_3216Metric_Pad1.33x1.80mm_HandSolder; Part Number CL31B106KBHNNNE; LCSC C89632
C63, C66: 100nF BST; C_0402_1005Metric_Pad0.74x0.62mm_HandSolder; Part Number 0402B104K160CT; LCSC C83056
C64, C65: 22uF 5V buck; C_0805_2012Metric_Pad1.18x1.45mm_HandSolder; Part Number CL21A226MAQNNNE; LCSC C45783
C67, C68: 22uF laser buck; C_0805_2012Metric_Pad1.18x1.45mm_HandSolder; Part Number CL21A226MAQNNNE; LCSC C45783
C69: 100pF FF; C_0402_1005Metric_Pad0.74x0.62mm_HandSolder; Part Number 0402CG101J500NT; LCSC C1546
C70: 22uF 100V; C_Elec_8x10.2; Part Number RVT2A220M0810 22UF 100V; LCSC C970665
D5, D6: SS14; D_SMA; Part Number SS14; LCSC C2480
J5: 24V DC IN; BarrelJack_OD5.5_ID2.5; Part Number DC-470-2.1GP; LCSC C194407
J6: CONN_RJ45; RJ45_Amphenol_RJHSE538X; Part Number R-RJ45R08P-C000; LCSC C386757
L1: 4.7uH; L_5.4x5.3_H3; Part Number MWSA0503S-4R7MT; LCSC C408410
L2: 10uH; L_4x4; Part Number WPN4020H100MT; LCSC C98364
R41: 2.49k MPD bias; R_0603_1608Metric_Pad0.98x0.95mm_HandSolder; Part Number 0603WAF2491T5E; LCSC C22908
R42, R44, R46, R48: 240R MPD sense; R_0603_1608Metric_Pad0.98x0.95mm_HandSolder; Part Number RTT032400FTP; LCSC C103446
R43, R45, R47, R49: 1k ADC; R_0603_1608Metric_Pad0.98x0.95mm_HandSolder; Part Number FRC0603F1001TS; LCSC C2907002
R61: 237k FB; R_0603_1608Metric_Pad0.98x0.95mm_HandSolder; Part Number FRC0603F2373TS; LCSC C2998117
R62: 22.1K FB; R_0402_1005Metric_Pad0.72x0.64mm_HandSolder; Part Number FRC0402F2212TS; LCSC C2929993
R63, R64: 10K; R_0603_1608Metric_Pad0.98x0.95mm_HandSolder; Part Number CRCW060310K0FKEA; LCSC C844918
U11: AP2112K-3.3; SOT-23-5; Part Number AP2112K-3.3TRG1; LCSC C51118
U12: INA4180A1; TSSOP-14_4.4x5mm_P0.65mm; Part Number INA4180A1IPWR; LCSC C2057528
U13: LM4040C50 5V; SOT-23; Part Number LM4040C50IDBZR; LCSC C69316
U14: AD7606BSTZ-4; LQFP-64_10x10mm_P0.5mm; Part Number AD7606BSTZ-4RL; LCSC C51512
U15: AP63205WU-7 5V BUCK; TSOT-23-6; Part Number AP63205WU-7; LCSC C2071056
U16: AP63200WU-7 9.3V BUCK; TSOT-23-6; Part Number AP63200WU-7; LCSC C2071868

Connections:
+3V3: C35.1, C49.1, C50.1, C55.1, R64.1, U11.5 (VOUT), U12.4 (VS), U14.6 (PAR/SER/BYTE SEL), U14.7 (STBY), U14.23 (VDRIVE), U14.34 (REF SELECT); also elsewhere on the board
/POWER_IO/ADC_CREFIN: C59.1, U14.42 (REFIN/REFOUT)
/POWER_IO/ADC_CREG1: C57.1, U14.36 (REGCAP)
/POWER_IO/ADC_CREG2: C58.1, U14.39 (REGCAP)
/POWER_IO/ADC_REFCAP: C60.1, U14.44 (REFCAPA), U14.45 (REFCAPB)
/POWER_IO/BUCK5_BST: C63.2, U15.6 (BST)
/POWER_IO/BUCK5_SW: C63.1, L1.1, U15.5 (SW)
/POWER_IO/LASER_BUCK_BST: C66.2, U16.6 (BST)
/POWER_IO/LASER_BUCK_SW: C66.1, L2.1, U16.5 (SW)
/POWER_IO/MPD_AMP1: R43.1, U12.1 (OUT1)
/POWER_IO/MPD_AMP2: R45.1, U12.7 (OUT2)
/POWER_IO/MPD_AMP3: R47.1, U12.8 (OUT3)
/POWER_IO/MPD_AMP4: R49.1, U12.14 (OUT4)
/POWER_IO/MPD_BIAS: C36.2, R41.1, R42.2, R44.2, R46.2, R48.2, U12.2 (IN-1), U12.6 (IN-2), U12.9 (IN-3), U12.13 (IN-4), U13.2 (A), U13.3 (*)
/POWER_IO/RJ45_LED_CONTACT: J6.12, R64.2
/POWER_IO/RJ45_PWR_DETECT: J6.10, R63.2
ADC_BUSY: U14.14 (BUSY); also elsewhere on the board
ADC_CS: U14.13 (CS); also elsewhere on the board
ADC_MISO_A: U14.24 (DB7/DOUTA); also elsewhere on the board
ADC_MISO_B: U14.25 (DB8/DOUTB); also elsewhere on the board
ADC_RESET: U14.11 (RESET); also elsewhere on the board
ADC_SCLK: U14.12 (RD/SCLK); also elsewhere on the board
CONVST: U14.9 (CONVSTA), U14.10 (CONVSTB); also elsewhere on the board
MPD1: C37.1, R43.2; also elsewhere on the board
MPD2: C38.1, R45.2; also elsewhere on the board
MPD3: C39.1, R47.2; also elsewhere on the board
MPD4: C40.1, R49.2; also elsewhere on the board
MPD_RAW1: R42.1, U12.3 (IN+1); also elsewhere on the board
MPD_RAW2: R44.1, U12.5 (IN+2); also elsewhere on the board
MPD_RAW3: R46.1, U12.10 (IN+3); also elsewhere on the board
MPD_RAW4: R48.1, U12.12 (IN+4)
VOUT1: U14.49 (V1); also elsewhere on the board
VOUT2: U14.51 (V2); also elsewhere on the board
VOUT3: U14.57 (V3); also elsewhere on the board
VOUT4: U14.59 (V4); also elsewhere on the board

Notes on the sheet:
Power & I/O - 24V barrel/RJ45 input, onboard AP63205 +5V buck, AP63200 laser buck, AD7606-4 ADC, monitor-PD front end
Inputs: J5 barrel center and J6 pins 4/5 -> VIN_24V; J5 sleeve/switch and J6 pins 7/8/9/11 -> GND.
RJ45: copied access-controller CONN_RJ45 symbol; J6 pins 10/12 use 10k LED/contact resistors to VIN_24V/+3V3.
Supplies: U15 AP63205 -> BUCK_5V/+5V, U16 AP63200 -> LASER_V+ ~=9.3V; raw 24V stays off laser anodes.

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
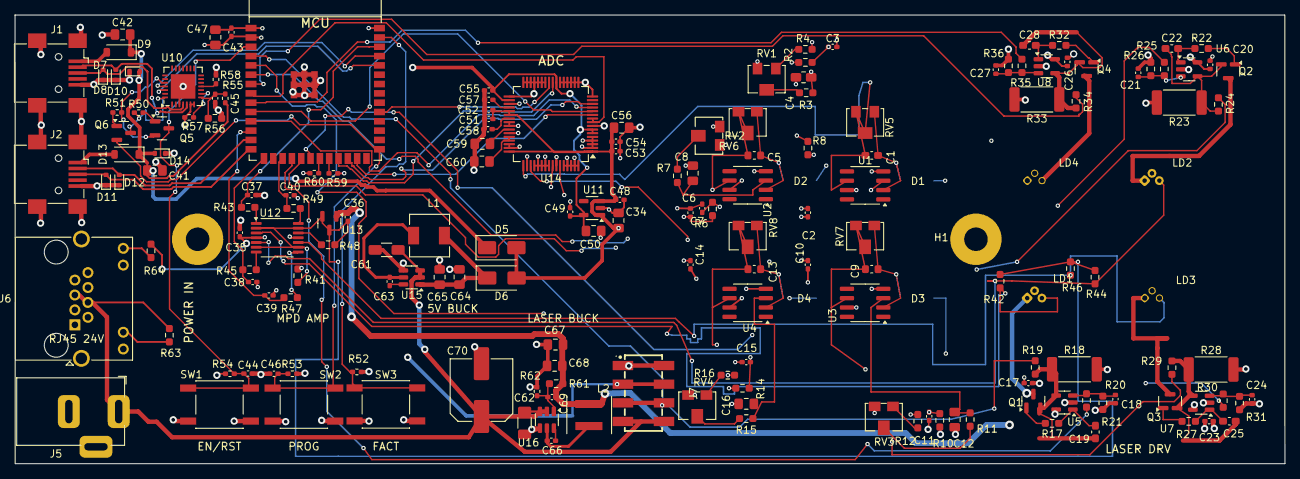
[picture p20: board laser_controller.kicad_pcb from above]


Board: 4 copper layers, 173.0 x 61.1 mm, 181 parts (8 on the bottom side), 110 nets.

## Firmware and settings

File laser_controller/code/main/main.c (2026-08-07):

#include <inttypes.h>
#include <stdbool.h>
#include <stddef.h>
#include <stdint.h>

#include "driver/gpio.h"
#if CONFIG_LC_ENABLE_LASER_PULSE_TEST
#include "driver/ledc.h"
#include "driver/usb_serial_jtag.h"
#include "esp_adc/adc_cali.h"
#include "esp_adc/adc_cali_scheme.h"
#include "esp_adc/adc_oneshot.h"
#endif
#include "driver/spi_master.h"
#include "esp_app_desc.h"
#include "esp_attr.h"
#include "esp_err.h"
#include "esp_idf_version.h"
#include "esp_log.h"
#include "esp_rom_sys.h"
#include "esp_system.h"
#include "esp_timer.h"
#include "freertos/FreeRTOS.h"
#include "freertos/task.h"

#include "ad7606_decode.h"
#include "laser_safety.h"
#include "laser_test_protocol.h"
#if CONFIG_LC_ENABLE_WEB_DASHBOARD
#include "laser_web.h"
#endif

enum {
    GPIO_PWM_IR = 10,
    GPIO_PWM_RED = 11,
    GPIO_PWM_GREEN = 12,
    GPIO_PWM_BLUE = 16,
    GPIO_ADC_CONVST = 15,
    GPIO_ADC_SCLK = 17,
    GPIO_ADC_CS = 18,
    GPIO_ADC_DOUTA = 21,
    GPIO_ADC_BUSY = 47,
    GPIO_ADC_RESET = 48,
};

static const char *TAG = "laser_controller";
static const uint64_t PWM_PIN_MASK =
    (1ULL << GPIO_PWM_IR) |
    (1ULL << GPIO_PWM_RED) |
    (1ULL << GPIO_PWM_GREEN) |
    (1ULL << GPIO_PWM_BLUE);

static laser_safety_t safety;
static spi_device_handle_t adc_spi;
static uint64_t conversion_count;
static uint64_t timing_overrun_count;
static volatile bool adc_busy_rise_latched;

static void IRAM_ATTR adc_busy_rise_isr(void *argument)
{
    (void)argument;
    adc_busy_rise_latched = true;
}

#if CONFIG_LC_ENABLE_LASER_PULSE_TEST
enum {
    TELEMETRY_CHANNEL_COUNT = 8,
    UART_LINE_CAPACITY = 128,
    USB_TELEMETRY_CAPACITY = 768,
    LASER_PWM_FREQUENCY_HZ = 10000,
    LASER_PWM_MAX_DUTY = 1023,
};

typedef struct {
    int raw[TELEMETRY_CHANNEL_COUNT];
    int millivolts[TELEMETRY_CHANNEL_COUNT];
} laser_telemetry_t;

typedef struct {
    bool active;
    bool latched;
    uint8_t channel_mask;
    uint16_t channel_duty_permille[LASER_TEST_CHANNEL_COUNT];
    uint16_t duty_permille;
    int64_t deadline_us;
} laser_pulse_t;

static const int LASER_PWM_GPIOS[LASER_TEST_CHANNEL_COUNT] = {
    GPIO_PWM_IR,
    GPIO_PWM_RED,
    GPIO_PWM_GREEN,
    GPIO_PWM_BLUE,
};
static const ledc_channel_t LASER_PWM_CHANNELS[LASER_TEST_CHANNEL_COUNT] = {
    LEDC_CHANNEL_0,
    LEDC_CHANNEL_1,
    LEDC_CHANNEL_2,
    LEDC_CHANNEL_3,
};
static const adc_channel_t TELEMETRY_CHANNELS[TELEMETRY_CHANNEL_COUNT] = {
    ADC_CHANNEL_3, /* GPIO4: ISENSE1 */
    ADC_CHANNEL_4, /* GPIO5: ISENSE2 */
    ADC_CHANNEL_5, /* GPIO6: ISENSE3 */
    ADC_CHANNEL_6, /* GPIO7: ISENSE4 */
    ADC_CHANNEL_1, /* GPIO2: MPD1 */
    ADC_CHANNEL_2, /* GPIO3: MPD2 */
    ADC_CHANNEL_7, /* GPIO8: MPD3 */
    ADC_CHANNEL_8, /* GPIO9: MPD4/spare */
};
static const gpio_num_t TELEMETRY_GPIOS[TELEMETRY_CHANNEL_COUNT] = {
    GPIO_NUM_4, /* ISENSE1 */
    GPIO_NUM_5, /* ISENSE2 */
    GPIO_NUM_6, /* ISENSE3 */
    GPIO_NUM_7, /* ISENSE4 */
    GPIO_NUM_2, /* MPD1 */
    GPIO_NUM_3, /* MPD2 */
    GPIO_NUM_8, /* MPD3 */
    GPIO_NUM_9, /* MPD4/spare */
};
static const char *const TELEMETRY_SIGNAL_NAMES[TELEMETRY_CHANNEL_COUNT] = {
    "ISENSE1",
    "ISENSE2",
    "ISENSE3",
    "ISENSE4",
    "MPD1",
    "MPD2",
    "MPD3",
    "MPD4_SPARE",
};
static const int ISENSE_HARD_CEILING_MV[LASER_TEST_CHANNEL_COUNT] = {
    450,
    300,
    850,
    1150,
};

static bool laser_pwm_initialized;
static uint8_t laser_direct_gpio_mask;
static bool telemetry_initialized;
static adc_oneshot_unit_handle_t telemetry_adc;
static adc_cali_handle_t telemetry_cali[TELEMETRY_CHANNEL_COUNT];
static laser_pulse_t pulse;
static char uart_line[UART_LINE_CAPACITY];
static size_t uart_line_length;
static uint8_t usb_stream_hz;
static bool usb_snapshot_requested;
#endif

static void force_all_lasers_off(void)
{
#if CONFIG_LC_ENABLE_LASER_PULSE_TEST
    if (laser_direct_gpio_mask != 0U) {
        for (uint8_t channel = 0; channel < LASER_TEST_CHANNEL_COUNT; ++channel) {
            if ((laser_direct_gpio_mask & (1U << channel)) != 0U) {
                gpio_set_level(LASER_PWM_GPIOS[channel], 0);
            }
        }
        laser_direct_gpio_mask = 0U;
    }
    if (laser_pwm_initialized) {
        for (size_t channel = 0; channel < LASER_TEST_CHANNEL_COUNT; ++channel) {
            ledc_set_duty(LEDC_LOW_SPEED_MODE, LASER_PWM_CHANNELS[channel], 0);
            ledc_update_duty(LEDC_LOW_SPEED_MODE, LASER_PWM_CHANNELS[channel]);
        }
        return;
    }
#endif
    gpio_set_level(GPIO_PWM_IR, 0);
    gpio_set_level(GPIO_PWM_RED, 0);
    gpio_set_level(GPIO_PWM_GREEN, 0);
    gpio_set_level(GPIO_PWM_BLUE, 0);
}

static esp_err_t configure_safe_gpio(void)
{
    const gpio_config_t pwm_config = {
        .pin_bit_mask = PWM_PIN_MASK,
        .mode = GPIO_MODE_OUTPUT,
        .pull_up_en = GPIO_PULLUP_DISABLE,
        .pull_down_en = GPIO_PULLDOWN_ENABLE,
        .intr_type = GPIO_INTR_DISABLE,
    };
    esp_err_t error = gpio_config(&pwm_config);
    if (error != ESP_OK) {
        return error;
    }
    force_all_lasers_off();

    const gpio_config_t adc_output_config = {
        .pin_bit_mask = (1ULL << GPIO_ADC_CONVST) | (1ULL << GPIO_ADC_RESET),
        .mode = GPIO_MODE_OUTPUT,
        .pull_up_en = GPIO_PULLUP_DISABLE,
        .pull_down_en = GPIO_PULLDOWN_ENABLE,
        .intr_type = GPIO_INTR_DISABLE,
    };
    error = gpio_config(&adc_output_config);
    if (error != ESP_OK) {
        return error;
    }
    gpio_set_level(GPIO_ADC_CONVST, 0);
    gpio_set_level(GPIO_ADC_RESET, 0);

    const gpio_config_t busy_config = {
        .pin_bit_mask = 1ULL << GPIO_ADC_BUSY,
        .mode = GPIO_MODE_INPUT,
        .pull_up_en = GPIO_PULLUP_DISABLE,
        .pull_down_en = GPIO_PULLDOWN_DISABLE,
        .intr_type = GPIO_INTR_POSEDGE,
    };
    error = gpio_config(&busy_config);
    if (error != ESP_OK) {
        return error;
    }
    error = gpio_install_isr_service(ESP_INTR_FLAG_IRAM);
    if (error != ESP_OK) {
        return error;
    }
    return gpio_isr_handler_add(GPIO_ADC_BUSY, adc_busy_rise_isr, NULL);
}

#if CONFIG_LC_ENABLE_LASER_PULSE_TEST
static esp_err_t configure_laser_pwm_channel(size_t channel)
{
    if (channel >= LASER_TEST_CHANNEL_COUNT) {
        return ESP_ERR_INVALID_ARG;
    }
    const ledc_channel_config_t channel_config = {
        .gpio_num = LASER_PWM_GPIOS[channel],
        .speed_mode = LEDC_LOW_SPEED_MODE,
        .channel = LASER_PWM_CHANNELS[channel],
        .intr_type = LEDC_INTR_DISABLE,
        .timer_sel = LEDC_TIMER_0,
        .duty = 0,
        .hpoint = 0,
        .sleep_mode = LEDC_SLEEP_MODE_NO_ALIVE_NO_PD,
        .flags.output_invert = 0,
    };
    esp_err_t error = ledc_channel_config(&channel_config);
    if (error != ESP_OK) {
        return error;
    }
    return gpio_input_enable((gpio_num_t)LASER_PWM_GPIOS[channel]);
}

static esp_err_t configure_laser_test_pwm(void)
{
    const ledc_timer_config_t timer_config = {
        .speed_mode = LEDC_LOW_SPEED_MODE,
        .duty_resolution = LEDC_TIMER_10_BIT,
        .timer_num = LEDC_TIMER_0,
        .freq_hz = LASER_PWM_FREQUENCY_HZ,
        .clk_cfg = LEDC_AUTO_CLK,
        .deconfigure = false,
    };
    esp_err_t error = ledc_timer_config(&timer_config);
    if (error != ESP_OK) {
        return error;
    }

    for (size_t channel = 0; channel < LASER_TEST_CHANNEL_COUNT; ++channel) {
        error = configure_laser_pwm_channel(channel);
        if (error != ESP_OK) {
            return error;
        }
        ESP_LOGI(
            TAG,
            "PWM_MAP channel=%s gpio=%d ledc_channel=%d",
            laser_test_channel_name(channel),
            LASER_PWM_GPIOS[channel],
            (int)LASER_PWM_CHANNELS[channel]
        );
    }
    const uint32_t configured_frequency =
        ledc_get_freq(LEDC_LOW_SPEED_MODE, LEDC_TIMER_0);
    if (configured_frequency != LASER_PWM_FREQUENCY_HZ) {
        ESP_LOGE(
            TAG,
            "PWM_TIMER_MISMATCH requested_hz=%d configured_hz=%" PRIu32,
            LASER_PWM_FREQUENCY_HZ,
            configured_frequency
        );
        return ESP_FAIL;
    }
    laser_pwm_initialized = true;
    force_all_lasers_off();
    return ESP_OK;
}

static esp_err_t configure_telemetry_adc(void)
{
    const adc_oneshot_unit_init_cfg_t unit_config = {
        .unit_id = ADC_UNIT_1,
        .clk_src = ADC_RTC_CLK_SRC_DEFAULT,
        .ulp_mode = ADC_ULP_MODE_DISABLE,
    };
    esp_err_t error = adc_oneshot_new_unit(&unit_config, &telemetry_adc);
    if (error != ESP_OK) {
        return error;
    }

    const adc_oneshot_chan_cfg_t channel_config = {
        .atten = ADC_ATTEN_DB_12,
        .bitwidth = ADC_BITWIDTH_12,
    };
    for (size_t index = 0; index < TELEMETRY_CHANNEL_COUNT; ++index) {
        error = adc_oneshot_config_channel(
            telemetry_adc,
            TELEMETRY_CHANNELS[index],
            &channel_config
        );
        if (error != ESP_OK) {
            return error;
        }

        const adc_cali_curve_fitting_config_t calibration_config = {
            .unit_id = ADC_UNIT_1,
            .chan = TELEMETRY_CHANNELS[index],
            .atten = ADC_ATTEN_DB_12,
            .bitwidth = ADC_BITWIDTH_12,
        };
        error = adc_cali_create_scheme_curve_fitting(
            &calibration_config,
            &telemetry_cali[index]
        );
        if (error != ESP_OK) {
            return error;
        }
    }
    telemetry_initialized = true;
    return ESP_OK;
}

static esp_err_t read_telemetry(laser_telemetry_t *telemetry)
{
    if (!telemetry_initialized || telemetry == NULL) {
        return ESP_ERR_INVALID_STATE;
    }
    for (size_t index = 0; index < TELEMETRY_CHANNEL_COUNT; ++index) {
        esp_err_t error = adc_oneshot_read(
            telemetry_adc,
            TELEMETRY_CHANNELS[index],
            &telemetry->raw[index]
        );
        if (error != ESP_OK) {
            return error;
        }
        error = adc_cali_raw_to_voltage(
            telemetry_cali[index],
            telemetry->raw[index],
            &telemetry->millivolts[index]
        );
        if (error != ESP_OK) {
            return error;
        }
    }
    return ESP_OK;
}

static esp_err_t read_telemetry_channel_average(
    size_t index,
    int *raw_average,
    int *millivolts
)
{
    enum { SAMPLE_COUNT = 16 };
    if (!telemetry_initialized || index >= TELEMETRY_CHANNEL_COUNT ||
        raw_average == NULL || millivolts == NULL) {
        return ESP_ERR_INVALID_ARG;
    }
    int64_t raw_sum = 0;
    for (unsigned sample = 0; sample < SAMPLE_COUNT; ++sample) {
        int raw = 0;
        const esp_err_t error = adc_oneshot_read(
            telemetry_adc,
            TELEMETRY_CHANNELS[index],
            &raw
        );
        if (error != ESP_OK) {
            return error;
        }
        raw_sum += raw;
    }
    *raw_average = (int)(raw_sum / SAMPLE_COUNT);
    return adc_cali_raw_to_voltage(
        telemetry_cali[index],
        *raw_average,
        millivolts
    );
}
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
void app_main(void)
{
    laser_safety_init(&safety);

    esp_err_t error = configure_safe_gpio();
    if (error != ESP_OK) {
        ESP_LOGE(TAG, "safe GPIO initialization failed: %s", esp_err_to_name(error));
        laser_safety_latch_fault(&safety, LASER_FAULT_ADC_INIT);
        remain_fault_latched();
    }
    force_all_lasers_off();
    log_boot_metadata();

#if CONFIG_LC_ENABLE_LASER_PULSE_TEST
    error = configure_laser_test_pwm();
    if (error == ESP_OK) {
        error = configure_telemetry_adc();
    }
    if (error == ESP_OK) {
        error = configure_test_command_transport();
    }
    if (error != ESP_OK) {
        ESP_LOGE(TAG, "laser-test peripheral initialization failed: %s", esp_err_to_name(error));
        latch_fault(LASER_FAULT_TELEMETRY_ADC);
        remain_fault_latched();
    }
#endif

    if ((1000U % CONFIG_LC_AD7606_SAMPLE_RATE_HZ) != 0U) {
        ESP_LOGE(
            TAG,
            "sample rate %d does not divide the 1000 Hz RTOS tick",
            CONFIG_LC_AD7606_SAMPLE_RATE_HZ
        );
        latch_fault(LASER_FAULT_ADC_INIT);
        remain_fault_latched();
    }

    error = initialize_adc_spi();
    if (error != ESP_OK) {
        ESP_LOGE(TAG, "ADC SPI initialization failed: %s", esp_err_to_name(error));
        latch_fault(LASER_FAULT_ADC_INIT);
        remain_fault_latched();
    }
    reset_adc();

    ad7606_sample_t sample = {0};
    laser_fault_t fault = acquire_sample(&sample);
    if (fault != LASER_FAULT_NONE) {
        latch_fault(fault);
        remain_fault_latched();
    }
    if (!laser_safety_mark_adc_ready(&safety)) {
        latch_fault(LASER_FAULT_ADC_INIT);
        remain_fault_latched();
    }

#if CONFIG_LC_ENABLE_LASER_PULSE_TEST
    laser_telemetry_t telemetry = {0};
    error = read_telemetry(&telemetry);
    if (error != ESP_OK) {
        ESP_LOGE(TAG, "telemetry ADC initial read failed: %s", esp_err_to_name(error));
        latch_fault(LASER_FAULT_TELEMETRY_ADC);
        remain_fault_latched();
    }
    ESP_LOGI(TAG, "laser-test ready; use a bounded local PULSE command");
#endif

#if CONFIG_LC_ENABLE_WEB_DASHBOARD
    error = laser_web_start();
    if (error != ESP_OK) {
        ESP_LOGE(TAG, "dashboard initialization failed: %s", esp_err_to_name(error));
        latch_fault(LASER_FAULT_WEB_INIT);
        remain_fault_latched();
    }
    publish_web_snapshot(&sample, &telemetry);
#endif

    const TickType_t sample_period = pdMS_TO_TICKS(
        1000U / CONFIG_LC_AD7606_SAMPLE_RATE_HZ
    );
    TickType_t last_wake = xTaskGetTickCount();

    for (;;) {
#if CONFIG_LC_ENABLE_LASER_PULSE_TEST
        bool command_processed = false;
#endif
        if (xTaskDelayUntil(&last_wake, sample_period) != pdTRUE) {
            ++timing_overrun_count;
#if CONFIG_LC_STRICT_SAMPLE_DEADLINE
            latch_fault(LASER_FAULT_ADC_TIMING_OVERRUN);
            remain_fault_latched();
#else
            last_wake = xTaskGetTickCount();
#endif
        }

#if CONFIG_LC_ENABLE_WEB_DASHBOARD
        if (laser_web_ota_in_progress() && pulse.active) {
            stop_output("ota");
        }
#endif

        const int64_t started_us = esp_timer_get_time();
        fault = acquire_sample(&sample);
        if (fault != LASER_FAULT_NONE) {
            latch_fault(fault);
            remain_fault_latched();
        }

#if CONFIG_LC_ENABLE_LASER_PULSE_TEST
        error = read_telemetry(&telemetry);
        if (error != ESP_OK) {
            ESP_LOGE(TAG, "telemetry ADC read failed: %s", esp_err_to_name(error));
            latch_fault(LASER_FAULT_TELEMETRY_ADC);
            remain_fault_latched();
        }
        if (!update_pulse(&telemetry)) {
            remain_fault_latched();
        }
        command_processed = service_test_commands();
#if CONFIG_LC_ENABLE_WEB_DASHBOARD
        laser_test_command_t web_command = {0};
        while (laser_web_receive_command(&web_command)) {
            apply_test_command(&web_command);
            command_processed = true;
        }
#endif
#endif

        ++conversion_count;
#if CONFIG_LC_ENABLE_WEB_DASHBOARD
        publish_web_snapshot(&sample, &telemetry);
#endif
#if CONFIG_LC_ENABLE_LASER_PULSE_TEST
        const bool usb_stream_due = usb_stream_hz > 0U &&
            (conversion_count % (CONFIG_LC_AD7606_SAMPLE_RATE_HZ / usb_stream_hz)) == 0U;
        if (usb_snapshot_requested || usb_stream_due) {
            usb_snapshot_requested = false;
            publish_usb_snapshot(&sample, &telemetry);
        }
#endif
#if CONFIG_LC_AD7606_LOG_EVERY_N > 0
        if ((conversion_count % CONFIG_LC_AD7606_LOG_EVERY_N) == 0U) {
            ESP_LOGI(
                TAG,
#if CONFIG_LC_ENABLE_LASER_PULSE_TEST
                "S=%" PRIu64 " AD=%d,%d,%d,%d I=%d,%d,%d,%d "
                "M=%d,%d,%d,%d IRAW=%d,%d,%d,%d MRAW=%d,%d,%d,%d "
                "ST=%d F=%08" PRIx32 " P=%u,%u",
                conversion_count,
                sample.counts[0],
                sample.counts[1],
                sample.counts[2],
                sample.counts[3],
                telemetry.millivolts[0],
                telemetry.millivolts[1],
                telemetry.millivolts[2],
                telemetry.millivolts[3],
                telemetry.millivolts[4],
                telemetry.millivolts[5],
                telemetry.millivolts[6],
                telemetry.millivolts[7],
                telemetry.raw[0],
                telemetry.raw[1],
                telemetry.raw[2],
                telemetry.raw[3],
                telemetry.raw[4],
                telemetry.raw[5],
                telemetry.raw[6],
                telemetry.raw[7],
                (int)safety.state,
                safety.fault_mask,
                pulse.active ? pulse.channel_mask : 0U,
                pulse.duty_permille
#else
                "sample=%" PRIu64 " ch1=%d ch2=%d ch3=%d ch4=%d "
                "overruns=%" PRIu64 " faults=0x%08" PRIx32,
                conversion_count,
                sample.counts[0],
                sample.counts[1],
                sample.counts[2],
                sample.counts[3],
                timing_overrun_count,
                safety.fault_mask
#endif
            );
        }
#endif

        if (!laser_safety_outputs_permitted(&safety)) {
            force_all_lasers_off();
        }
#if CONFIG_LC_ENABLE_LASER_PULSE_TEST
        if (command_processed) {
            /* Command handling can emit multiple synchronous diagnostics and
             * intentionally exceed this one sampling period. Start a fresh
             * strict period after that bounded control-plane work. */
            last_wake = xTaskGetTickCount();
            continue;
        }
#endif
        const int64_t elapsed_us = esp_timer_get_time() - started_us;
        const int64_t period_us = 1000000LL / CONFIG_LC_AD7606_SAMPLE_RATE_HZ;
        if (elapsed_us >= period_us) {
            ++timing_overrun_count;
#if CONFIG_LC_STRICT_SAMPLE_DEADLINE
            latch_fault(LASER_FAULT_ADC_TIMING_OVERRUN);
            remain_fault_latched();
#endif
        }
    }
}

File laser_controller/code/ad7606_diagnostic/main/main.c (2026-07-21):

#include <inttypes.h>
#include <stdbool.h>
#include <stdint.h>

#include "driver/gpio.h"
#include "esp_attr.h"
#include "esp_err.h"
#include "esp_log.h"
#include "esp_rom_sys.h"
#include "freertos/FreeRTOS.h"
#include "freertos/task.h"

enum {
    GPIO_PWM_IR = 10,
    GPIO_PWM_RED = 11,
    GPIO_PWM_GREEN = 12,
    GPIO_PWM_BLUE = 16,
    GPIO_ADC_CONVST = 15,
    GPIO_ADC_SCLK = 17,
    GPIO_ADC_CS = 18,
    GPIO_ADC_DOUTA = 21,
    GPIO_ADC_DOUTB = 38,
    GPIO_ADC_BUSY = 47,
    GPIO_ADC_RESET = 48,
    DIAGNOSTIC_CONVERSIONS = 8,
    CONTINUOUS_LOG_EVERY = 10,
};

typedef struct {
    int busy_before;
    int busy_immediate;
    int busy_after_1us;
    int busy_after_3us;
    uint32_t busy_edges;
    uint32_t douta;
    uint32_t doutb;
} conversion_observation_t;

static const char *TAG = "ad7606_diag";
static volatile uint32_t busy_edge_count;

static void IRAM_ATTR busy_edge_isr(void *argument)
{
    (void)argument;
    ++busy_edge_count;
}

static void force_lasers_off(void)
{
    gpio_set_level(GPIO_PWM_IR, 0);
    gpio_set_level(GPIO_PWM_RED, 0);
    gpio_set_level(GPIO_PWM_GREEN, 0);
    gpio_set_level(GPIO_PWM_BLUE, 0);
}

static esp_err_t configure_gpio(void)
{
    const gpio_config_t laser_outputs = {
        .pin_bit_mask = (1ULL << GPIO_PWM_IR) | (1ULL << GPIO_PWM_RED) |
                        (1ULL << GPIO_PWM_GREEN) | (1ULL << GPIO_PWM_BLUE),
        .mode = GPIO_MODE_OUTPUT,
        .pull_up_en = GPIO_PULLUP_DISABLE,
        .pull_down_en = GPIO_PULLDOWN_ENABLE,
        .intr_type = GPIO_INTR_DISABLE,
    };
    esp_err_t error = gpio_config(&laser_outputs);
    if (error != ESP_OK) {
        return error;
    }
    force_lasers_off();

    const gpio_config_t adc_outputs = {
        .pin_bit_mask = (1ULL << GPIO_ADC_CONVST) | (1ULL << GPIO_ADC_SCLK) |
                        (1ULL << GPIO_ADC_CS) | (1ULL << GPIO_ADC_RESET),
        .mode = GPIO_MODE_OUTPUT,
        .pull_up_en = GPIO_PULLUP_DISABLE,
        .pull_down_en = GPIO_PULLDOWN_DISABLE,
        .intr_type = GPIO_INTR_DISABLE,
    };
    error = gpio_config(&adc_outputs);
    if (error != ESP_OK) {
        return error;
    }
    gpio_set_level(GPIO_ADC_CONVST, 0);
    gpio_set_level(GPIO_ADC_SCLK, 0);
    gpio_set_level(GPIO_ADC_CS, 1);
    gpio_set_level(GPIO_ADC_RESET, 0);

    const gpio_config_t adc_inputs = {
        .pin_bit_mask = (1ULL << GPIO_ADC_DOUTA) | (1ULL << GPIO_ADC_DOUTB) |
                        (1ULL << GPIO_ADC_BUSY),
        .mode = GPIO_MODE_INPUT,
        .pull_up_en = GPIO_PULLUP_DISABLE,
        .pull_down_en = GPIO_PULLDOWN_DISABLE,
        .intr_type = GPIO_INTR_DISABLE,
    };
    error = gpio_config(&adc_inputs);
    if (error != ESP_OK) {
        return error;
    }

    error = gpio_install_isr_service(ESP_INTR_FLAG_IRAM);
    if (error != ESP_OK && error != ESP_ERR_INVALID_STATE) {
        return error;
    }
    error = gpio_set_intr_type(GPIO_ADC_BUSY, GPIO_INTR_ANYEDGE);
    if (error != ESP_OK) {
        return error;
    }
    return gpio_isr_handler_add(GPIO_ADC_BUSY, busy_edge_isr, NULL);
}

static void reset_adc(uint32_t high_us)
{
    gpio_set_level(GPIO_ADC_RESET, 1);
    esp_rom_delay_us(high_us);
    gpio_set_level(GPIO_ADC_RESET, 0);
    esp_rom_delay_us(100);
}

static void read_serial_outputs(uint32_t *douta, uint32_t *doutb)
{
    uint32_t a = 0;
    uint32_t b = 0;

    gpio_set_level(GPIO_ADC_SCLK, 0);
    gpio_set_level(GPIO_ADC_CS, 0);
    esp_rom_delay_us(2);

    a = (uint32_t)gpio_get_level(GPIO_ADC_DOUTA);
    b = (uint32_t)gpio_get_level(GPIO_ADC_DOUTB);
    for (unsigned bit = 1; bit < 32; ++bit) {
        gpio_set_level(GPIO_ADC_SCLK, 1);
        esp_rom_delay_us(2);
        gpio_set_level(GPIO_ADC_SCLK, 0);
        esp_rom_delay_us(2);
        a = (a << 1U) | (uint32_t)gpio_get_level(GPIO_ADC_DOUTA);
        b = (b << 1U) | (uint32_t)gpio_get_level(GPIO_ADC_DOUTB);
    }
    gpio_set_level(GPIO_ADC_SCLK, 1);
    esp_rom_delay_us(2);
    gpio_set_level(GPIO_ADC_SCLK, 0);
    gpio_set_level(GPIO_ADC_CS, 1);

    *douta = a;
    *doutb = b;
}

static conversion_observation_t convert_and_read(void)
{
    conversion_observation_t observation = {0};
    observation.busy_before = gpio_get_level(GPIO_ADC_BUSY);

    gpio_set_level(GPIO_ADC_CONVST, 0);
    esp_rom_delay_us(10);
    const uint32_t edges_before = busy_edge_count;
    gpio_set_level(GPIO_ADC_CONVST, 1);
    observation.busy_immediate = gpio_get_level(GPIO_ADC_BUSY);
    esp_rom_delay_us(1);
    observation.busy_after_1us = gpio_get_level(GPIO_ADC_BUSY);
    esp_rom_delay_us(2);
    observation.busy_after_3us = gpio_get_level(GPIO_ADC_BUSY);
    esp_rom_delay_us(17);
    observation.busy_edges = busy_edge_count - edges_before;

    read_serial_outputs(&observation.douta, &observation.doutb);
    gpio_set_level(GPIO_ADC_CONVST, 1);
    return observation;
}

static const char *pull_name(gpio_pull_mode_t pull)
{
    switch (pull) {
    case GPIO_FLOATING:
        return "floating";
    case GPIO_PULLUP_ONLY:
        return "pullup";
    case GPIO_PULLDOWN_ONLY:
        return "pulldown";
    default:
        return "unexpected";
    }
}
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

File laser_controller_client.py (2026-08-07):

"""Persistent USB-first client for the Vivonics laser/ADC controller."""
from __future__ import annotations

import copy
import json
import logging
import os
import threading
import time
from typing import Any, Callable
from urllib.error import URLError
from urllib.request import Request, urlopen


LOG = logging.getLogger(__name__)
PROTOCOL_PREFIX = b"VLC1 "
CHANNELS = (
    ("IR", "Infrared", 780, True),
    ("RED", "Red", 650, True),
    ("GREEN", "Green", 520, True),
    ("BLUE", "Blue", 450, False),
)


class LaserControllerClient:
    """Own one serial connection and expose a transport-neutral live snapshot.

    USB is authoritative whenever a versioned telemetry line has arrived within
    ``usb_stale_s``. Wi-Fi polling/control is the automatic fallback.
    """

    def __init__(
        self,
        usb_path: str | None = None,
        wifi_url: str | None = None,
        *,
        stream_hz: int = 25,
        usb_stale_s: float = 0.8,
        clock: Callable[[], float] = time.monotonic,
    ) -> None:
        self.usb_path = usb_path or os.environ.get("VIVONICS_LASER_CONTROLLER_USB", "/dev/ttyACM0")
        self.wifi_url = (wifi_url or os.environ.get(
            "VIVONICS_LASER_CONTROLLER_WIFI_URL", "http://192.168.1.179"
        )).rstrip("/")
        self.stream_hz = stream_hz
        self.usb_stale_s = usb_stale_s
        self._clock = clock
        self._stop = threading.Event()
        self._thread: threading.Thread | None = None
        self._serial: Any | None = None
        self._write_lock = threading.Lock()
        self._condition = threading.Condition()
        self._snapshot: dict[str, Any] | None = None
        self._snapshot_version = 0
        self._last_usb_at = 0.0
        self._last_wifi_at = 0.0
        self._usb_open = False
        self._wifi_reachable = False
        self._failover_count = 0
        self._last_command_transport: str | None = None
        self._last_error: str | None = None
        self._usb_parse_errors = 0
        self._usb_reconnects = 0

    def start(self) -> None:
        if self._thread and self._thread.is_alive():
            return
        self._stop.clear()
        self._thread = threading.Thread(target=self._run, name="laser-controller", daemon=True)
        self._thread.start()

    def close(self) -> None:
        self._stop.set()
        try:
            self.off(wait_for_confirmation=False)
        except Exception:
            LOG.exception("Unable to force laser controller off during close")
        serial_port = self._serial
        if serial_port is not None:
            try:
                serial_port.close()
            except Exception:
                pass
        if self._thread:
            self._thread.join(timeout=2.0)

    def status(self) -> dict[str, Any]:
        now = self._clock()
        usb_age_ms = (now - self._last_usb_at) * 1000 if self._last_usb_at else None
        wifi_age_ms = (now - self._last_wifi_at) * 1000 if self._last_wifi_at else None
        usb_fresh = usb_age_ms is not None and usb_age_ms <= self.usb_stale_s * 1000
        wifi_fresh = wifi_age_ms is not None and wifi_age_ms <= 1000
        snapshot_transport = self._snapshot.get("transport") if self._snapshot else None
        active = "usb" if usb_fresh else (
            "wifi" if wifi_fresh and snapshot_transport == "wifi" else "unavailable"
        )
        return {
            "activeTransport": active,
            "usbConnected": self._usb_open,
            "usbFresh": usb_fresh,
            "usbPath": self.usb_path,
            "usbSampleAgeMs": round(usb_age_ms, 1) if usb_age_ms is not None else None,
            "wifiReachable": self._wifi_reachable,
            "wifiUrl": self.wifi_url,
            "wifiSampleAgeMs": round(wifi_age_ms, 1) if wifi_age_ms is not None else None,
            "streamRateHz": self.stream_hz,
            "failoverCount": self._failover_count,
            "lastCommandTransport": self._last_command_transport,
            "usbReconnects": self._usb_reconnects,
            "usbParseErrors": self._usb_parse_errors,
            "lastError": self._last_error,
        }

    def snapshot(self) -> dict[str, Any] | None:
        with self._condition:
            payload = copy.deepcopy(self._snapshot)
        if payload is None:
            return None
        payload["connection"] = self.status()
        payload["receivedAtMs"] = int(time.time() * 1000)
        return payload

    def wait_until_available(self, timeout_s: float = 5.0) -> bool:
        """Wait for fresh USB or Wi-Fi telemetry after a controller reboot."""
        deadline = time.monotonic() + max(0.0, timeout_s)
        while True:
            if self.status()["activeTransport"] != "unavailable":
                return True
            remaining = deadline - time.monotonic()
            if remaining <= 0:
                return False
            with self._condition:
                self._condition.wait(timeout=min(0.1, remaining))

    def set_levels(
        self,
        *,
        red: int = 0,
        green: int = 0,
        infrared: int = 0,
        blue: int = 0,
        wait_for_confirmation: bool = True,
    ) -> dict[str, Any]:
        levels = [infrared, red, green, blue]
        if any(not isinstance(level, int) or level < 0 or level > 255 for level in levels):
            raise ValueError("laser levels must be integers in the range 0..255")
        duties = [round(level * 1000 / 255) for level in levels]
        return self._set_permille(duties, wait_for_confirmation=wait_for_confirmation)

    def off(self, *, wait_for_confirmation: bool = True) -> dict[str, Any]:
        return self._set_permille([0, 0, 0, 0], wait_for_confirmation=wait_for_confirmation)

    def _set_permille(self, duties: list[int], *, wait_for_confirmation: bool) -> dict[str, Any]:
        usb_ready = self.status()["usbFresh"]
        if usb_ready:
            command = "OFF\n" if not any(duties) else "LEVELS " + " ".join(map(str, duties)) + "\n"
            if self._write_usb(command.encode("ascii")):
                self._last_command_transport = "usb"
                if not wait_for_confirmation or self._wait_for_duties(duties, timeout_s=0.45):
                    return {"ok": True, "transport": "usb", "dutiesPermille": duties}
                self._record_failover("USB command was not confirmed; using Wi-Fi")

        response = self._write_wifi(duties)
        self._last_command_transport = "wifi"
        return {"ok": True, "transport": "wifi", "dutiesPermille": duties, "controller": response}
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

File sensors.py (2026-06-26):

"""Optional I2C sensor support for the Vivonics Pi bench.

The IMX477 camera is still the primary C1/X1 detector. These sensors are
auxiliary readouts for intensity drift, crude spectral checks, and eventual
photodiode cross-checks.
"""
from __future__ import annotations

import time
import os
from dataclasses import dataclass, field
from math import sqrt
from typing import Any


@dataclass
class SensorReading:
    name: str
    ok: bool
    channels: dict[str, float] = field(default_factory=dict)
    error: str | None = None
    timestamp_s: float = field(default_factory=time.time)

    def as_dict(self) -> dict[str, Any]:
        return {
            "name": self.name,
            "ok": self.ok,
            "channels": self.channels,
            "error": self.error,
            "timestamp_s": self.timestamp_s,
        }


class SensorSuite:
    """Read the ordered TSL2591 and AS7341 I2C modules when present."""

    def __init__(
        self,
        enable_tsl2591: bool = True,
        enable_as7341: bool = True,
        enable_ad7606: bool | None = None,
    ) -> None:
        self._i2c = None
        self._tsl2591 = None
        self._as7341 = None
        self._ad7606 = None
        self._ad7606_avg_samples = max(1, _env_int("VIVONICS_AD7606_AVG_SAMPLES", 1))
        self._init_errors: dict[str, str] = {}
        if enable_ad7606 is None:
            enable_ad7606 = _env_bool("VIVONICS_AD7606_ENABLE", False)

        if enable_tsl2591 or enable_as7341:
            self._i2c = self._open_i2c()

        if self._i2c is not None and enable_tsl2591:
            self._tsl2591 = self._init_tsl2591()
        if self._i2c is not None and enable_as7341:
            self._as7341 = self._init_as7341()
        if enable_ad7606:
            self._ad7606 = self._init_ad7606()

    def availability(self) -> dict[str, Any]:
        return {
            "tsl2591": self._tsl2591 is not None,
            "as7341": self._as7341 is not None,
            "ad7606": self._ad7606 is not None,
            "ad7606_avg_samples": self._ad7606_avg_samples,
            "bpw34": "ad7606_ch1" if self._ad7606 is not None else "external_adc_required",
            "init_errors": self._init_errors,
        }
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

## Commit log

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2026-05-22 feat(bench): add laser GPIO control, multiply demo, and service upgrades
    Add laser_gpio.py for direct PWM control of red/green lasers and
    multiply_demo.py for bR analog multiplication experiments. Upgrade
    bench_service.py with direct picamera2 capture at 148fps, experiment
    orchestration, and green self-modulation measurement. Update jig model
    and deployment docs.
    [jig.blend, jig.stl]
2026-05-25 feat(bench): add reactor jig and pigpio laser control
    [jig.3mf, jig.blend, reactor.3mf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]
2026-05-25 fix(bench): fall back to rpi gpio laser pwm
    [laser_gpio.py]
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2026-05-31 feat(circuits): reactor TIA OPA380 schematic + JLCPCB BOM + datasheets
    2x OPA380AID single-channel TIA front-end to recover the ~1% red M-state
    modulation the passive 100k load could not resolve. KiCad v7 schematic with
    a generator that keeps the schematic and JLCPCB BOM in sync, plus the
    OPA380/BPW34 datasheets.
    [reactor_tia.kicad_sch, reactor_tia_bom_jlcpcb.csv]
2026-05-31 chore(jig): update jig model + add electro-photonic coupler 3mf/stl
    [electro-photonic-coupler.3mf, electro-photonic-coupler.stl, jig.blend]
2026-06-01 refactor(circuits): redraw reactor TIA schematic with signal flow, power symbols, concise BOM
    Rewrote gen_reactor_tia_sch.py to emit a hand-laid-out, left-to-right schematic (D1 -> U1 TIA with R_f||C_f feedback -> Sallen-Key U2 -> J1), real wires, +5V/GND power symbols, and net labels. Regene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
    [reactor_tia.kicad_sch, reactor_tia_bom_jlcpcb.csv]
2026-06-01 feat(circuits): dual-channel reactor TIA (1 OPA380 per channel)
    Retire the single-channel 2-stage TIA (TIA + Sallen-Key). The board is now two independent channels, one OPA380AID TIA each (BPW34 -> TIA -> V_CHn), sharing one VBIAS divider. Anti-alias rides on the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
    Generator is the source of truth (parametric, N-channel). 14 SMT / 18 total, 8 nets, netlist-validated. README rewritten to per-channel topology + new BOM.
    [reactor_tia.kicad_sch, reactor_tia_bom_jlcpcb.csv]
2026-06-03 chore(models): reorganize jig CAD into models/, add test-tube holders
    Move jig designs into models/jig/ and add models (test-tube holders + downloaded 12mm base). Keep Blender sources (*.blend); large regenerable exports (Untitled.stl/3mf, sliced gcode) are NOT stored 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
    [1Tube.stl, 24-tubes.blend, 2Tubes.stl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]
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2026-06-17 feat: red weight bit precision — fast mmap, within-capture differential
    7 write durations × 8 reps, 200ms continuous capture per trial
    Early vs late frames compared within same capture (no inter-read drift)
    Result: M-state signal confirmed at 0.096% ΔT, but trial-to-trial drift
    (21 ct) exceeds multi-level signal range (8 ct). Binary only at 650nm.
    570nm probe needed for multi-bit weights.
2026-06-26 feat: add laser controller board and bench updates
    [jig.blend, laser_blue.kicad_sch, laser_controller.kicad_pcb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]
2026-06-26 fix: report split rail groups in release gate
    [check_laser_controller_release_gate.py]
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2026-06-28 fix(circuits): import mcu sheet and laser footprints
    [laser_blue.kicad_sch, laser_controller.kicad_pcb, laser_controller.kicad_sch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]
2026-06-28 fix(circuits): restore placed laser controller pcb
    [laser_controller.kicad_pcb]
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2026-06-29 fix pcb update footprint identity
    [laser_controller.kicad_pcb, laser_controller.kicad_sch, laser_controller_bom_jlcpcb.csv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]
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2026-07-01 Datasheet system audit: new verification checks, part notes, and PCB revisions
    [laser_controller.kicad_pcb, laser_controller_bom_jlcpcb.csv, power_io.kicad_sch]
2026-07-01 Add Edge.Cuts board outline (173x72mm) around placed components
    [laser_controller.kicad_pcb]
2026-07-01 Fix D1 SFH2201 pad rotation to match D2/D3/D4 (remove stray 90deg pad rotation)
    [laser_controller.kicad_pcb]
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2026-07-01 Center PDs and lasers on board Y axis (16mm spacing, symmetric about y=110.44)
    [laser_controller.kicad_pcb]
2026-07-01 Rotate laser controller backups and sync latest PCB state
    [laser_controller.kicad_pcb]
2026-07-01 Add 3x M3 mounting holes (GND, 3.2mm drill, 7mm pad) for case mounting
    [laser_controller.kicad_pcb]
2026-07-01 Rotate laser controller backup, sync latest PCB with mounting holes
    [laser_controller.kicad_pcb]
2026-07-01 Fix: revert to known-good, add GND vias at JLCPCB min (0.6/0.3), presets in pro file only
    [laser_controller.kicad_pcb]
2026-07-01 Fix D11/J6 pad overlap — move D11 from (45.15,104.13) to (42,104)
    [laser_controller.kicad_pcb]
2026-07-01 Remove GND fanout traces — keep vias only, zone pour handles connections (AC pattern)
    [laser_controller.kicad_pcb]
2026-07-01 Remove all auto-generated routing — zero segments/vias, zero overlaps, clean base for manual routing
    [laser_controller.kicad_pcb]
2026-07-02 Final clean: zero routing, zero overlaps — ready for manual routing
    [laser_controller.kicad_pcb]
2026-07-02 Restore from 6c15cf9 + D11 fix only — zero corruption, zero overlaps
    [laser_controller.kicad_pcb]
2026-07-02 Set JLCPCB DRC rules (0.127mm clearance) + restore track/via presets
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2026-07-02 Add net classes from generator — fix DRC routing start point violations
    [laser_controller.kicad_pcb]
2026-07-02 Fix Power_Rails net class: min trace 0.25mm (was 0.60, too wide for QFP pads)
    [laser_controller.kicad_pcb]
2026-07-02 Fix Power_Rails net class + rotate backups
    [laser_controller.kicad_pcb]
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2026-07-02 Re-add net classes (overwritten by KiCad) + Power_Rails fix
    [laser_controller.kicad_pcb]
2026-07-02 Add 30 clean GND vias (0.6/0.3mm) + net classes + Power_Rails fix — zero via overlaps
    [laser_controller.kicad_pcb]
2026-07-02 Add 46 GND fanout vias + traces — connected to pads, zero geometric overlaps
    [laser_controller.kicad_pcb]
2026-07-02 GND vias placed at pad edge + 0.35mm — ultra-close fanout, zero overlaps
    [laser_controller.kicad_pcb]
2026-07-02 fix(pcb): save current power plane cleanup
    [laser_controller.kicad_pcb]
2026-07-02 fix(pcb): remove internal routed traces
    [laser_controller.kicad_pcb]
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2026-07-02 fix(pcb): remove dangling trace stubs
    [laser_controller.kicad_pcb]
2026-07-03 chore(pcb): checkpoint current layout before power plane cleanup
    Rotate backup snapshots ahead of restructuring power planes into
    standard 24V/GND/3V3/5V regions and de-overlapping PD/laser components.
    [laser_controller.kicad_pcb]
2026-07-03 fix(pcb): eliminate all 25 component courtyard overlaps
    Zero footprint-body overlaps and zero different-net pad overlaps now,
    verified against a fresh courtyard-polygon analysis (not just pad
    bboxes). Worst offender was J6 (RJ45) grossly overlapping the whole
    J2/D11/D12/D13 USB cluster (10.75x6.23mm); the rest were per-channel
    TIA/laser-driver decoupling caps squeezed against their op-amp/FET by
    the HandSolder footprint variants being larger than the original
    template spacing assumed.
    Verified against the project's own PLACEMENT_CHECKS: identical 71/111
    pass/fail set before and after -- these moves introduced zero new
    placement-distance violations and fixed zero pre-existing ones (those
    71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
    [laser_controller.kicad_pcb]
2026-07-03 fix(pcb): pull D8/C42 back from the board edge
    D8 and C42 landed with negative edge clearance (-0.708mm / -0.055mm)
    after the courtyard-overlap fix -- close enough to J1's cluster that
    the solver satisfied the no-overlap constraint by pushing them partly
    off the board outline instead. Re-solved both with an explicit board-
    edge margin this time; still zero courtyard/pad overlaps.
    Caught this because routing generated against the previous positions
    produced segments with endpoints outside the board outline near D8 --
    a good reminder to check edge clearance, not just inter-component
    clearance, whenever placement changes.
    [laser_controller.kicad_pcb]
2026-07-03 fix(pcb): stop the router from putting vias on pads, add 45-degree corner chamfering, fix stale absolute-coordinate corridors
    - _via_clear_sized no longer exempts same-net pads from clearance
    checking (SAME_NET_VIA_PAD_CLEARANCE_MM = 0.15mm) -- this was the
    root cause of vias landing centered on pads: the fallback logic
    treated a via directly on a same-net pad as "clear" since same-net
    copper touching same-net copper isn't a DRC violation, even though
    it's bad practice outside a deliberate via-in-pad process this board
    doesn't use. Removed the explicit via_in_pad_fallbacks escape hatch
    in emit_ground_plane_fanout_segments now that it can never legally
    fire.
    - Fixed the board-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
    [pcb_critical_routes.py]
2026-07-03 fix(pcb): regenerate routing with clean power planes and full connectivity closure
    Full re-route of laser_controller.kicad_pcb using the fixed router
    engine (no via-on-pad, 45-degree chamfering, board-relative corridors)
    against the now-overlap-free hand placement, plus a generic
    connectivity-closure pass for nets no CRITICAL_ROUTE_LINKS/POWER_ROUTE_LINKS
    entry covered at all (ADC bus signals, photodiode bias networks, AD7606
    reference network).
    Verified (all via check_laser_controller_pcb.py's own functions, not
    self-reported):
    - 0 footprint courtyard/pad overlaps (was 25)
    - 0 different-net pad overlaps (was 4)
    - 0 dangling copper
    - 0 copper routed outside the board outline (was 13 -- two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
    [laser_controller.kicad_pcb]
2026-07-03 fix(pcb): close more long cross-board nets (larger route-search budget)
    Follow-up connectivity pass with a 6x larger A* search budget (15000 vs
    2500 cells) and a general-search fallback when no predefined corridor
    lane is clear end-to-end. Closed several more PWM/ADC-bus links
    (PWM1, PWM2, ADC_CS/SCLK/RESET/MISO_A, ISENSE1/2/4).
    72/110 multi-pad nets now fully connected + 7 zone/rail-covered (was
    70+7); via-on-pad down to 1 instance, and that one is J2 pin 4, an
    intentionally-unconnected USB ID pin
    (check_laser_controller_pcb.intentional_unnetted_pad_names already
    allowlists it). 0 dangling copper, 0 pad overlaps, 0 copper outside
    the board outline, unchanged from the previous commit.
    Rema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
    [laser_controller.kicad_pcb]
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2026-07-03 fix(pcb): strip all routing, rebuild power zones to match access-controller
    The previous auto-generated routing was rejected on review as low
    quality (thick/tangled traces, crude bends) even though it had decent
    net connectivity -- stripped entirely (0 segments, 0 vias) for a
    from-scratch re-route.
    Also fully reworked the power zones after the previous session's
    small-isolated-pours approach was also rejected as overcomplicated.
    Now matches ~/projects/access-controller/circuits/controller/
    access-controller.kicad_pcb's pattern: a single full-board GND flood
    on In1.Cu (no outer-layer GND fill -- F.Cu/B.Cu are pure signal
    layers now), and In2.Cu split into exactly two simple, non-overlapping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
    [laser_controller.kicad_pcb]
2026-07-03 wip(pcb): manual routing in progress (KiCad GUI)
    Real hand-routing progress since the routing strip: 1130 segments,
    188 vias added. Verified before committing: file parses cleanly (180
    footprints, no dup refs), 0 different-net pad overlaps, 0 copper
    outside the board outline, 1 dangling segment (likely mid-edit).
    Connectivity: 85/110 multi-pad nets fully connected + 4 covered by a
    required zone/rail pour, 21 still split -- ahead of where the
    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
    [laser_controller.kicad_pcb]
2026-07-03 feat(pcb): route 17 unconnected signal nets on laser_controller
    Route ADC control (BUSY/CS/MISO_A/MISO_B/RESET/CONVST), current sense
    (ISENSE1-4), PWM (PWM2-4), and AD7606 bypass/refcap nets.
    - 98 new segments + 14 new vias added before zone blocks
    - Short routes on F.Cu with 45-degree chamfered corners
    - Cross-board routes via B.Cu with 0.6mm/0.3mm vias
    - All previously-dead nets confirmed connected (pad-to-segment <0.02mm)
    - Verified loads and exports cleanly via kicad-cli 7.0.11
    Note: fine-pitch IC DRC clearance must be set in Board Setup GUI
    (not embeddable in KiCad 7.0.11 PCB file format).
    [laser_controller.kicad_pcb]
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2026-07-03 feat(pcb): route remaining unconnected pads, add pad clearance overrides
    - Bridge VOUT1-3 AD7606 analog inputs to TIA output networks (18 segments)
    - Bridge MPD_BIAS isolated resistors to main bias group (9 segments)
    - Add (clearance 0.15) to all U9 (ESP32-S3) and U14 (AD7606 LQFP-64) SMD pads
    - Fixes pin-too-close DRC violations on fine-pitch ICs
    - Verified: kicad-cli export svg passes, 0 signal nets unconnected
    [laser_controller.kicad_pcb]
2026-07-03 fix(pcb): remove 98 segments/vias overlapping different-net pads
    Cleared traces passing through pads of different nets across 38 nets
    including ADC, ISENSE, PWM, VOUT, laser cathode, and zone traces.
    Line-by-line removal preserves file integrity (balanced parens).
    Verified: kicad-cli export svg passes.
    [laser_controller.kicad_pcb]
2026-07-03 fix(pcb): remove overlapping traces passing through pads
    [laser_controller.kicad_pcb]
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2026-07-03 fix(pcb): add pad clearance 0.2mm to LD1-LD4 laser diode footprints
    [laser_controller.kicad_pcb]
2026-07-03 fix(pcb): rotate all silk reference labels to 0deg for consistent readability
    [laser_controller.kicad_pcb]
2026-07-03 feat(pcb): add silk outlines, section labels, pin labels, dividers
    - Circle outlines around LD1-4 laser diodes (TO-18/TO-56)
    - Rectangle outlines around D1-4 photodiodes with cathode marks
    - Board section labels: TIA IR/RED/GREEN/BLUE, LASER drivers, MCU, ADC, POWER
    - Connector labels: USB-UART, USB-ESP, 24V IN, LASER HARNESS
    - Dashed divider lines between board sections
    [laser_controller.kicad_pcb]
2026-07-03 revert: remove messy silk additions (LD labels, section labels, dividers)
    Keeping only the 0deg silk rotation fix. The added graphic elements
    overlapped pads and other labels and were redundant.
    [laser_controller.kicad_pcb]
2026-07-03 fix(pcb): reposition all silk screen reference labels to avoid overlaps
    - Adjusted fp_text reference positions for all components
    - Moved labels from default footprint origins to clear positions
    - Applied rotations where needed for readability
    - Fixed label hide/show state for H2 mounting hole
    - Minor placement adjustment for C38 (63.35 vs 63.355)
    - Updated kicad_prl settings
    [laser_controller.kicad_pcb]
2026-07-03 fix(pcb): add missing 3D models and fix model paths
    - Installed kicad-packages3d (5.8GB, 424MB download)
    - Created 6 custom WRL 3D models for custom parts:
    - Potentiometer_Bourns_3224W_Vertical (8 Bourns trim pots)
    - LaserDiode_TO18-D5.6-3 and TO56-3 (4 laser diodes)
    - Osram_SFH2201 (4 photodiodes)
    - L_Taiyo-Yuden_NR-50xx (buck inductor)
    - L_6.3x6.3_H3 (shielded power inductor)
    - Fixed ESP32-S3-WROOM-1 model path: 3rd-party -> system RF_Module.3dshapes
    - Fixed USB Mini-B model: Wuerth -> Lumberg (available in kicad-packages3d)
    - Updated all custom part model paths to use KIPRJMOD/packages3d
    - All 29 unique 3D model paths now resolve correctly (0 missing)
    - Models oriented correctly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
    [laser_controller.kicad_pcb]
2026-07-03 fix(pcb): improve 3D models - proper geometry, materials, and orientations
    - Replaced primitive box/cylinder models with detailed IndexedFaceSet meshes
    - Added proper material definitions (ambient, diffuse, specular, shininess, transparency)
    - Fixed ESP32-S3-WROOM-1: restored correct Espressif STEP model (18x19mm real)
    with proper offset (-9, -9.75) from ~/circuits/kicad-libraries
    - Bourns 3224W: added body with beveled edges, brass adjust screw with slot,
    three J-leads, pin 1 marking dot
    - SFH2201: clear silicone body with proper transparency, cathode mark,
    gold terminal pads
    - LaserDiode TO-18: metal can with flange, lens window, orientation tab,
    3 pins extending through board
    - La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
    [laser_controller.kicad_pcb]
2026-07-04 fix(pcb): fix 3D model paths for KiCad 7 compatibility, correct laser diode and inductor offsets
    - Replace all 135 KICAD6_3DMODEL_DIR references with KICAD7_3DMODEL_DIR
    - Fix LD1-LD4 laser diode model offsets: (0,0,0) -> (1,0,0) to center can body on footprint courtyard
    - Fix L1 inductor model offset: (0,0,0) -> (-0.65,0,0) to center on asymmetric pads
    - Add board renders: SVG, PNG, and STEP 3D export
    [laser_controller.kicad_pcb]
2026-07-04 feat(fab): generate JLCPCB gerbers, BOM, and POS files
    - Add 4-layer gerber files with drill files and job file
    - Update BOM with missing connectors (J5, J6) and laser diodes (LD1-LD4)
    - Generate SMD-only POS/CPL file (172 placements)
    - Include gerber zip ready for JLCPCB upload
    [laser_controller-B_Cu.gbl, laser_controller-B_Mask.gbs, laser_controller-B_Paste.gbp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]
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2026-07-04 Fix sensitive TIA PCB routing
    [laser_controller.kicad_pcb, laser_controller_bom_jlcpcb.csv]
2026-07-04 Fix J7 schematic source guardrails
    [mcu.kicad_sch]
2026-07-04 Fix PCB staging outline guardrail
    [check_pcb_staging.py, gen_pcb.py]
2026-07-04 Fix USB PCB routing policy
    [laser_controller.kicad_pcb]
2026-07-04 Fix laser control PCB layer vias
    [laser_controller.kicad_pcb]
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2026-07-04 Make segment clearance audit opt-in
    [check_laser_controller_pcb.py]
2026-07-04 Make trace-pad clearance audit opt-in
    [check_laser_controller_pcb.py]
2026-07-04 Make via-pad clearance audit opt-in
    [check_laser_controller_pcb.py]
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2026-07-04 Resolve USB connector source match
    [laser_controller_bom_jlcpcb.csv, mcu.kicad_sch]
2026-07-04 Tighten buck input layout geometry
    [laser_controller-B_Cu.gbl, laser_controller-B_Mask.gbs, laser_controller-B_Paste.gbp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]
2026-07-04 Resolve USB layout geometry review
    [check_layout_review_geometry.py]
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2026-07-05 Resolve focused analog layout geometry
    [laser_controller-B_Cu.gbl, laser_controller-B_Mask.gbs, laser_controller-B_Paste.gbp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]
2026-07-05 Fix PCB copper clearance violations
    [laser_controller.kicad_pcb]
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2026-07-05 Resolve SS14 and trimmer source signoffs
    [check_laser_controller_release_readiness.py, check_part_notes_completeness.py, check_source_documents.py]
2026-07-05 Resolve direct laser footprint signoff
    [check_laser_controller_release_readiness.py, check_laser_current_budget.py, check_part_notes_completeness.py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]
2026-07-05 Resolve return path layout signoff
    [check_laser_controller_release_readiness.py, check_source_documents.py, generate_laser_controller_audit_tables.py]
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2026-07-05 Resolve PCB body overlaps
    [laser_controller.kicad_pcb]
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2026-07-05 Checkpoint schematic ERC errors
    [laser_controller-B_Cu.gbl, laser_controller-B_Mask.gbs, laser_controller-B_Paste.gbp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]
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2026-07-05 Fix signal photodiode pad geometry
    [laser_controller-B_Cu.gbl, laser_controller-B_Mask.gbs, laser_controller-B_Paste.gbp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]
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2026-07-05 Reset KiCad layout session state
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2026-07-05 Fix optical-side assembly placement
    [laser_controller-B_Cu.gbl, laser_controller-B_Mask.gbs, laser_controller-B_Paste.gbp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]
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2026-07-06 Fix J7 SMT header 3D model
    [laser_controller.kicad_pcb]
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2026-07-06 Replace short-stock R41 assembly part
    [laser_controller.kicad_pcb, laser_controller_bom_jlcpcb.csv, laser_controller_full_procurement.csv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]
2026-07-06 Fix JLCPCB placement origin
    [laser_controller_pos.csv]
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2026-07-06 Fix JLCPCB connector assembly package
    [laser_controller-B_Cu.gbr, laser_controller-B_Mask.gbr, laser_controller-B_Paste.gbr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]
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2026-07-06 Fix laser controller JLCPCB connector assembly package
    [laser_controller-B_Cu.gbr, laser_controller-B_Mask.gbr, laser_controller-B_Paste.gbr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]
2026-07-06 Fix JLCPCB connector placement package
    [laser_controller.kicad_pcb, laser_controller_bom_jlcpcb.csv, laser_controller_full_procurement.csv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]
2026-07-06 Fix J7 assembly clearance and regenerate JLC package
    [laser_controller-B_Cu.gbr, laser_controller-B_Mask.gbr, laser_controller-B_Paste.gbr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]
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2026-07-07 Fix JLC assembly release for laser controller
    Repair OPA380/Bourns orientation gates, substitute C70 with JLC C970665, and regenerate BOM/CPL/Gerber/JLC package artifacts.
    Verified with run_laser_controller_review.py, check_jlcpcb_order_package.py, orientation/polarity PCB gate, and staged git diff whitespace check.
    [laser_controller-B_Cu.gbr, laser_controller-B_Mask.gbr, laser_controller-B_Paste.gbr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]
2026-07-14 chore(review): laser-controller release-gate + JLCPCB order journal updates
    Regenerated KiCad DRC/ERC/net reports, firmware-validation template,
    review gate, and the 2026-07-06 JLCPCB order journal / signoff records
    during the 2026-07-12..14 production-readiness audit.
    [first_article_firmware_validation_template.csv]
2026-07-14 docs(review): JLCPCB order — 07-07 transcript shows corrected files WERE re-uploaded
    Bench Codex transcript (2026-07-07) has direct portal evidence: order page
    'laser_controller_gerbers - Automatically saved, last updated 7 July 13:54',
    plus operator directives to rebuild 'to send to jlcpcb'. Revises the identity
    packet from 'likely mirrored' to 'likely corrected; verify final version attached'.
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2026-07-26 fix(laser-controller): reboot on stale active output
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2026-08-07 feat(bench): drive laser controller over USB with Wi-Fi fallback
    Replace the Pi GPIO light path with the ESP32-S3 four-source controller as
    the default bench driver. `laser_controller_client.py` owns /dev/ttyACM0
    persistently, normalizes ADC telemetry, and falls back to the controller's
    HTTP endpoint when USB goes stale. The service exposes the telemetry
    snapshot and an SSE stream, and `RawPulseMeasurer` accepts a light setter so
    pulse timing routes through the controller instead of pigpio. The legacy
    GPIO path stays available via VIVONICS_LIGHT_DRIVER=gpio.
    Firmware (0.3.4-dashboard) gains the host side of that protocol: LEVELS,
    STREAM and SNAPSHOT commands, USB telemetry publishing on the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
    [jig.blend, laser-controller-housing.stl, lens-holder.3mf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]
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
